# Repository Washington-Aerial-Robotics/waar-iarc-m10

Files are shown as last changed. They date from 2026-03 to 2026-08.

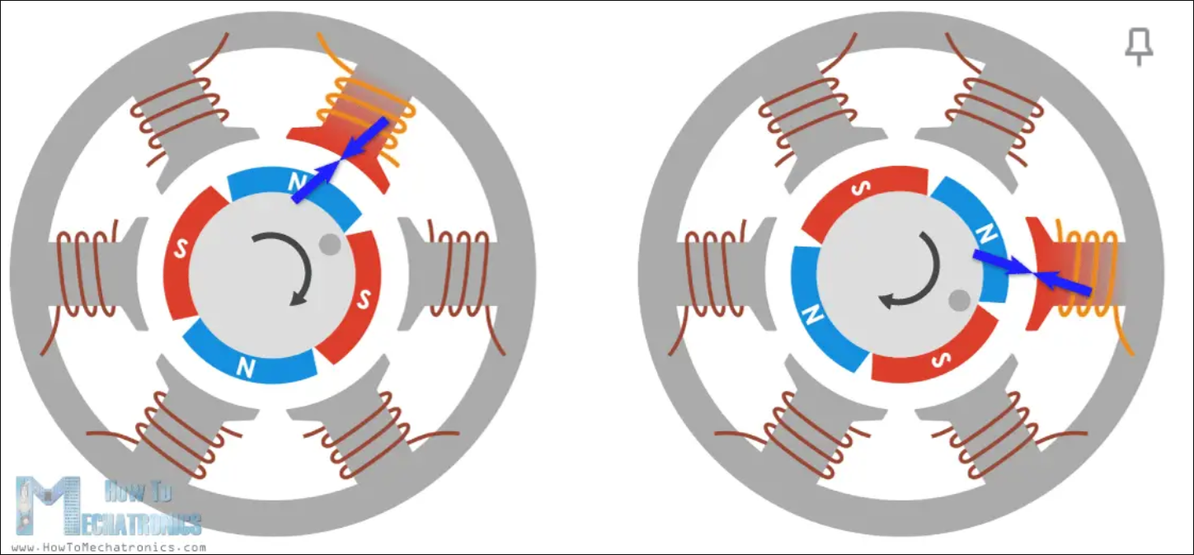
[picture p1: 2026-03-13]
ESP32/docs/images/ESC_MOTOR_BLDC.png

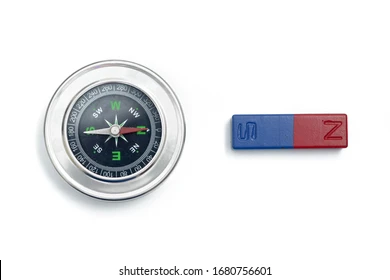
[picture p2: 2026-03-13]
ESP32/docs/images/ESC_MAGNET.png

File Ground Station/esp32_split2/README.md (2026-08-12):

# Flutter Drone Controller GUI

## Overview

This repository implements a **cross-platform Flutter-based drone control interface** for real-time communication with an ESP32 flight controller over TCP/Wi-Fi.

The application provides:

* live TCP console communication (send raw test/debug packets, watch raw firmware output)
* dual joystick flight controls
* ARM / DISARM / KILL safety controls
* voice commands (basic movement, hover, stop)
* responsive portrait + landscape layouts

---

## Getting Started

### Prerequisites

* Flutter SDK, **stable channel** (this project pins `sdk: ^3.9.2` in `pubspec.yaml` — run `flutter --version` and `flutter doctor` to confirm your install satisfies it).
* A phone (Android or iOS) or desktop target to run on. Voice control (`speech_to_text`) is the one feature that's only verified on mobile — don't assume it works on Windows/macOS/Linux builds.
* The drone powered on, with its flight firmware running (`ESP32/KAF_Drone`).

### Install & run

```bash
cd "Ground Station/esp32_split2"
flutter pub get
flutter devices        # confirm your target device/emulator is visible
flutter run            # or pick a device explicitly: flutter run -d <device-id>
```

You can also launch it from VS Code using the configurations in `.vscode/launch.json` (`esp32_split2`, plus profile/release variants).

Platform permissions the app needs are already declared:

* **Android** (`android/app/src/main/AndroidManifest.xml`): `RECORD_AUDIO` (voice control) and `INTERNET` (TCP socket to the drone).
* **iOS** (`ios/Runner/Info.plist`): `NSMicrophoneUsageDescription` and `NSSpeechRecognitionUsageDescription`.

If you add other platforms later, double-check they have equivalent permissions — network/mic access is not implicitly granted everywhere.

---

## Connecting to the drone

The app does **not** join Wi-Fi networks itself — it only opens a TCP socket to an IP/port you give it. You have to join the drone's Wi-Fi network at the OS level (phone Settings → Wi-Fi) *before* connecting from inside the app.

By default, the drone boots as its own open Wi-Fi access point:

* **SSID:** `KAF_Quadcopter_Drone`
* **Password:** none (open network)
* **Drone IP once connected:** `192.168.1.240`
* **TCP port:** `70` (hardcoded in firmware — `WiFiServer server = WiFiServer(70)` in `periph_wifi.cpp`)

> **Heads up:** the Console tab's IP/port fields currently default to `172.20.10.8` / `80` — leftovers from a previous test setup, not the drone's actual defaults. For a stock drone in its default AP mode, clear those fields and enter `192.168.1.240` and `70` instead. If your drone has been reconfigured to join an existing network (STA mode) or a different port, use whatever IP/port it was actually assigned there.

The drone's firmware only accepts **one TCP client at a time** — if another ground station (or a stale connection) is already attached, a new connection attempt will hang or fail until that one disconnects.

### Step by step

1. Power on the drone. It starts broadcasting `KAF_Quadcopter_Drone`.
2. On your phone, join that Wi-Fi network in system settings.
3. Open the app → **Console** tab.
4. Set **Target Drone ID** (single character, default `A` — must match the drone's configured ID).
5. Set **Drone IP** to `192.168.1.240` and **Port** to `70` (see note above).
6. Tap **Connect to drone**. You should see `Connecting…` then `Connected` in the log, and the connection status icon turn green.
7. Use **Send PING** to sanity-check the link — you should see a logged reply.

---

## Using the app

### Console tab

Low-level debug view. Connect/disconnect, change target drone ID, and fire off individual test packets:

* **Send PING** — round-trip check that the link is alive.
* **Get IP** — asks the drone to report its Wi-Fi info.
* **Get Pos** — requests the drone's current position/flight status.
* **Test Control** — sends a single motor-command packet with all four motors at 0.5, independent of the joysticks (useful for a quick bench test with props off).

All traffic is logged as raw hex in **Drone Printout**.

### Remote tab (primary flight interface)

* **Left stick** — throttle (up/down) / yaw (left/right).
* **Right stick** — pitch (forward/back) / roll (left/right).
* **ARM** — starts the app's control loop, which sends motor commands to the drone 4 times per second (every 250ms) based on current stick position.
* **DISARM** — zeroes all stick values and stops the control loop.
* **KILL** — immediately zeroes controls, stops the loop, *and* sends a dedicated kill packet to the drone's firmware (this is the one button that reaches the drone even if the local loop isn't running).
* Live readout of throttle/yaw/pitch/roll is shown in the HUD — note this reflects the app's own stick state, not telemetry reported back by the drone.

**Safety notes:**
* You must be connected *and* armed before sticks or voice commands do anything — the controls are disabled otherwise.
* Once "reconnect after KILL" happens (i.e. you've hit KILL), you must disconnect and reconnect before arming again.

### Voice control

Available on the Remote tab once armed. Tap the mic button and speak one phrase per command (recognized as a single short utterance, not continuous dictation):

| Say | Effect |
|---|---|
| "up" / "go up" / "move up" / "ascend" | increases throttle a step |
| "down" / "go down" / "move down" / "descend" | decreases throttle a step |
| "hover" / "maintain altitude" / "hold altitude" | sets throttle to a fixed hover value, centers pitch/roll/yaw |
| "stop" / "hold" / "stop moving" / "center controls" | centers pitch/roll/yaw, keeps current throttle |
| "forward" / "move forward" / "go forward" | pitches forward briefly, then auto-recenters |
| "backward" / "back" / "move backward" / "go backward" | pitches backward briefly, then auto-recenters |
| "move left" / "slide left" / "strafe left" | rolls left briefly, then auto-recenters |
| "move right" / "slide right" / "strafe right" | rolls right briefly, then auto-recenters |
| "rotate left" / "turn left" / "yaw left" | yaws left briefly, then auto-recenters |
| "rotate right" / "turn right" / "yaw right" | yaws right briefly, then auto-recenters |

Directional commands (forward/back/left/right/rotate) automatically recenter after ~750ms; throttle commands (up/down/hover) persist until changed again.

---

## Architecture

```text
Flutter UI Layer
│
├── Console Screen      — connect/disconnect, raw test packets, log view
├── Remote Control Screen — joysticks, ARM/DISARM/KILL, voice panel
│
▼
Controller Layer
│
├── DroneController        — connection state, stick state, safety commands, 4Hz TX loop
└── VoiceCommandController — wraps speech_to_text, maps phrases to DroneController calls
│
▼
Protocol Layer
│
└── drone_protocol.dart — builds/parses the binary packet format, message-type constants
│
▼
Networking Layer
│
└── TcpClient — raw dart:io Socket, TX/RX byte logging
│
▼
ESP32 firmware (../../ESP32/KAF_Drone)
```

State is shared via `provider`: `main.dart` sets up `TcpClient` → `DroneController` → `VoiceCommandController`, in that dependency order.

---

## Networking protocol

Communication is a **binary packet protocol** over a raw TCP socket (not line-delimited text).

### Packet layout

```text
byte 0: toId        — target device ID (single byte, e.g. 'A' = 0x41)
byte 1: fromId       — sender device ID (app is always 0x47 'G')
byte 2: messageType  — command code (see drone_protocol.dart / ESP32 communication.h)
byte 3: messageId    — rolling sequence number
bytes 4+: payload    — command-specific (e.g. 4 little-endian floats for motor commands)
```

Message-type constants live in `lib/protocol/drone_protocol.dart` and must match `ESP32/KAF_Drone/src/core/communication.h` on the firmware side exactly — they're maintained by hand on both sides, so re-check them against the firmware header if you add or change a command type.

### Motor control packets

Sent by the armed control loop at **4Hz (every 250ms)**: stick values are curve-shaped, mixed into 4 motor values via a standard X-quad mixer, and packed as 4 little-endian 32-bit floats (16-byte payload) behind the standard 4-byte header.

---

## Current file structure

```text
lib/
│
├── main.dart
│
├── controllers/
│   ├── drone_controller.dart
│   └── voice_command_controller.dart
│
├── protocol/
│   └── drone_protocol.dart
│
├── services/
│   └── tcp_client.dart
│
├── screens/
│   ├── drone_tcp_console.dart
│   ├── drone_remote_control.dart
│   └── beta_remote_preview.dart   (UI sandbox — not wired into the app's navigation)
│
└── widgets/
    ├── connect_panel.dart
    ├── log_view.dart
    └── voice_control_panel.dart
```

---

## Known gaps

* No telemetry is actually parsed or displayed from the drone yet — the "live" readout on the Remote tab is the app's own stick state, not anything reported back over the wire.
* ARM/DISARM are local-only; no packet is sent to the drone for either (KILL is the exception — it does send a real packet).
* No automated tests yet.

---

## Tech stack

* Flutter / Dart
* Provider (state management)
* `speech_to_text` (voice recognition)
* Raw TCP sockets (`dart:io`)
* ESP32 firmware backend (`ESP32/KAF_Drone`)

---

## Purpose

This project is being developed as a **real-time drone control GUI prototype** to be used by Washington Aerial Robotics.

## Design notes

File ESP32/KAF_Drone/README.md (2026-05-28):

# KAF Drone Flight Control Software
This is the repositorry for an ESP32 based quadcopter flight controller written in C-like C++ designed for the Washington Aerial Robotics RSO at University of Washington. This flight software is capable of semi-autonomous flight, swarm coordination with other quadcopters, and custom input control. It is able to execute 4-th order polynomial trajectories, position waypoints, direct acceleration control, and manual mode inputs. Some additional features include a web-based ground station and manual controller as well as both indoor and GPS position tracking.

## Setup Instructions

1. Download the contents of the ```waar-iarc-m10/ESP32/KAF_Drone``` directory from the WAAR GitHub [repository](https://github.com/Washington-Aerial-Robotics/waar-iarc-m10/tree/main/ESP32/KAF_Drone), and extract its contents if necessary.
2. From the download, identify the  ```KAF_Drone``` folder, and move this folder to the file location of ```C:\Users\[USERNAME]\Documents\Arduino\libraries\ ``` on your local computer.
3. Check that the ArduinoIDE on your computer has been properly installed and configured. If not, follow the instructions listed in the new member onboarding instructions document provided by Francisco.
4. Open ```C:\Users\[USERNAME]\Documents\Arduino\libraries\KAF_Drone\flashing_examples\firmware_full\firmware_full.ino``` in ArduinoIDE.
5. Connect your flight controller or ESP32 devboard to your computer, then flash the firmware_full Arduino sketch.
6. Verify that the flight controller is operational by checking for the appearance of a WiFi network named "KAF_Quadcopter_Drone" and by a proper serial port print-out at a baudrate of 115200.
7. Connect to the "KAF_Quadcopter_Drone" network, open a web browser, then go to the IP address ```192.168.1.240``` to access the web server ground station.

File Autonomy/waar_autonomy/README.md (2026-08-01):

# WAAR Autonomy — Single-Drone Corridor Explorer

A simulation of a single drone exploring an unknown hazardous environment and certifying a safe passage corridor from start to goal. The codebase follows **Clean Architecture** so every algorithmic layer is independently testable and replaceable.

---

## Setup

```bash
conda env create -f environment.yml
conda activate waar-autonomy
```

---

## Run

```bash
python sim.py                  # animated (default seed 42)
python sim.py --seed 7         # different map
python sim.py --no-anim        # headless, prints progress to console
python sim.py --hazards 40     # denser hazard field
python sim.py --delay 0.02     # slow down animation frame rate
```

---

## What the Simulation Does

The drone starts in the bottom-left corner of an unknown grid and must find and certify a **safe corridor** to the top-right goal.

### Three-Map Architecture

| Map | Grid scale | Contents | Accessible to |
|-----|---|---|---|
| **Map 1** — Ground truth | Fine (`80×60`) | True hazard positions | Infrastructure only — hidden from planner |
| **Map 2** — Visited blocks | Block (`20×15`) | Blocks the drone has entered | Domain `WorldModel` |
| **Map 3** — Detected map | Fine (`80×60`) | `UNKNOWN / FREE / HAZARD / INFLATED` | All use cases |

The fine grid is `K=4` cells per block side, so a `20×15` block grid becomes an `80×60` fine grid.

### Cell States (Map 3)

| State | Colour | Meaning |
|---|---|---|
| `UNKNOWN` | Dark | Not yet visited |
| `FREE` | Light grey | Visited, no hazard |
| `HAZARD` | Red | Confirmed hazard cell |
| `INFLATED` | Orange | Safety buffer around a hazard (radius 3.5 fine cells) |

### Per-Tick Loop

```
UC1  observe_block    → reveal K×K fine cells from Map 1 into Map 3
                        recompute inflation buffer if a hazard was found
UC2  compute_corridor → A* from start to goal on Map 3
                        UNKNOWN cells cost 4× (optimistic planning)
UC3  certify?         → corridor is certified if:
                          clearance ≥ 2.0 fine cells from nearest hazard
                          coverage  = 100% FREE cells (no UNKNOWN on path)
UC4  score_frontiers  → rank unvisited border blocks by:
                          −(travel_cost + goal_cost) + 4.0 × cert_gain
                        cert_gain = UNKNOWN cells on current corridor path
     move drone       → teleport to highest-scoring frontier block
```

---

## Project Structure

```
sim.py                              ← CLI entry point (thin wrapper)

src/
  domain/
    types.py                        ← K, cell states, block↔fine helpers
    world_model.py                  ← WorldModel: map2 (visited) + map3 (detected)
    drone_state.py                  ← DroneState: block + fine-cell position

  ports/
    ground_truth_port.py            ← Protocol: is_hazard(fx, fy)

  adapters/
    sim_ground_truth_adapter.py     ← Wraps GroundTruthMap for the port

  use_cases/
    types.py                        ← CertificationResult DTO
    update_world_model.py           ← UC1: observe block + recompute inflation
    compute_best_corridor.py        ← UC2: A* on fine grid
    evaluate_and_certify_corridor.py← UC3: clearance + coverage check
    score_frontiers_corridor_aware.py← UC4: reverse-Dijkstra + frontier scoring

  application/
    simulator.py                    ← Simulator: wires UC1→UC4 per tick

  infrastructure/
    env/ground_truth_map.py         ← GroundTruthMap (map1, hidden)
    env/map_factory.py              ← Seeded random hazard placement
    visualization/renderer.py       ← build_truth_image / build_detected_image

  experiments/
    config.py                       ← Config dataclass (all tunable parameters)
    run_sim.py                      ← run_headless, run_animated, main()

tests/                              ← Mirrors src/ layout, 43 tests
```

### Layer Import Rules

```
domain/       →  no imports from any other src/ layer
ports/        →  domain/ only
use_cases/    →  domain/, ports/ only
adapters/     →  domain/, ports/, infrastructure/
application/  →  all layers
experiments/  →  all layers (entry points)
```

---

## Configuration

All parameters live in [src/experiments/config.py](src/experiments/config.py):

| Parameter | Default | Effect |
|---|---|---|
| `block_cols` / `block_rows` | 20 / 15 | Grid dimensions in blocks |
| `n_hazards` | 25 | Number of hazard cells placed at random |
| `inflation_radius` | 3.5 | Safety buffer radius (fine cells) |
| `unknown_cost` | 4.0 | A* penalty per UNKNOWN fine cell |
| `min_clearance_cells` | 2.0 | Certification: min distance from any hazard |
| `min_coverage_ratio` | 1.0 | Certification: fraction of path cells that must be FREE |
| `w_cert` | 4.0 | Scoring weight for corridor-overlap uncertainty |
| `max_ticks` | 600 | Simulation budget |

---

## Tests

```bash
pytest              # 43 tests across all layers
pytest tests/domain/
pytest tests/use_cases/
pytest tests/application/   # includes full integration test (seed 42, tick 263)
```

---

## Example Output (headless)

```
Seed=42  blocks=20x15  fine=80x60  K=4  hazards=25
  tick=  50  corridor=yes  clearance=3.61  coverage=94%
  tick= 100  corridor=yes  clearance=3.61  coverage=94%
  tick= 150  corridor=yes  clearance=3.61  coverage=94%
  tick= 200  corridor=yes  clearance=3.61  coverage=95%
  tick= 250  corridor=yes  clearance=3.61  coverage=90%
  tick= 263  corridor=yes  clearance=3.61  coverage=100%
elapsed=4.64s

✅  CERTIFIED at tick 263  clearance=3.61 fine-cells  path_len=93 fine-cells
```

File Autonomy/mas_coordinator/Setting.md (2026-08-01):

# A) For Each drone (×4) 

### 1. `explorer_node` (Kevin - Skipp what he did here)
---

### 2. `p2p_sync_node` 

* Implements **Scheme B sync window**: neighbor graph + hello/ack + missing delta exchange

* Performs **belief fusion**:

  * mine belief clustering / confidence update
  * (optional) tile uncertainty fusion

* **Subscribes/Publishes:**

```
/team/pose_beacon
/team/sync_hello
/team/sync_ack
/team/mine_delta
(optional) /team/tile_delta
```

* (optional) publishes locally:

```
/drone_i/local_belief
```

---

### 3. `p2p_task_node` 

* Fully **P2P task auction system**

Components:

* announce
* claim
* result
* claim window

The **winner sends `task_cmd` to the local explorer** (interrupting exploration).

* **Subscribes/Publishes:**

```
/team/task_announce
/team/task_claim
/team/task_result
```

* **Local subscriptions**

```
/drone_i/mine_candidates
/drone_i/status
```

---

### 4. `mission_logic_node`

(merge it into `p2p_task_node` or independent)

Responsibilities:

* Runs the **State Machine + Behavior Tree runner**
  (each drone runs its own copy)
* Manages:

  * timers
  * geofence
  * time thresholds
  * state transitions
* Sends `task_cmd` to the local explorer
* (optional) broadcasts `mode_beacon` for team observation/consistency

---

# B) State Machine Definition

```
BOOT → SURVEY → VERIFY_TAG → PATH_VERIFY → CONVERGE → FINISH
```

For each state we define:

* **Entry condition**
* **Exit condition / transition**
* **Primary objective**
* **Possible P2P task types**

---

# 1) BOOT

### Objective

System initialization: network ready, localization ready.

### Entry

* System startup automatically enters **BOOT**

### Actions

(Not part of the main BT — usually an initialization sequence)

* Initialize ROS2 publishers/subscribers
* Initialize FastDDS domain
* Start publishing `pose_beacon`
  (even if still at origin)
* Create neighbor table (can start empty)
* Start sync node (able to receive hello/ack)

### Exit → SURVEY

Conditions:

```
pose_valid == true
explorer_node_ready == true
time_since_start < timeout_boot
```

Optional:

```
at least N_min_neighbors pose_beacon detected
```

(In simulation this requirement can be skipped)

---

# 2) SURVEY

### Objective

Maximize **coverage**, accumulate **mine beliefs**, maintain **team safety**, and keep **P2P synchronization active**.

### Entry

* From **BOOT**
* Or return from **VERIFY_TAG**

### Exit

```
→ VERIFY_TAG
    if local drone wins a verify task auction

→ PATH_VERIFY
    if remaining_time < T_path_verify_start (recommended: 120 s)

→ CONVERGE
    if remaining_time < T_converge_start (recommended: 90 s)

→ FINISH
    if remaining_time < T_finish (e.g., 5–10 s)

→ FAILSAFE (optional)
    severe risk (unsolvable collision / control failure)
```

### Possible P2P Tasks During SURVEY

* `VERIFY_TAG` (mine candidate verification)

Optional:

* `YIELD` (collision avoidance)
  but usually handled locally by the safety layer.

---

# 3) VERIFY_TAG

### Objective

Perform **close-range verification of a mine candidate**
(e.g., AprilTag / close inspection).

### Entry

* Drone wins `VERIFY_TAG(task_id)` during claim window

OR

* Local detection with deterministic self-assignment
  (not recommended — causes duplicate verification)

### Exit

```
→ SURVEY
    task completed (confirmed / rejected / uncertain)

→ CONVERGE / PATH_VERIFY
    if time thresholds are reached

→ FAILSAFE
    geofence violation or unresolved collision
```

### Task Completion Conditions

* Reach target radius `r_verify` (e.g., 1–2 m)
* Stay for `t_dwell` (e.g., 2–5 s)
* Acquire tag evidence or fail
* Publish `/team/task_result`

---

# 4) PATH_VERIFY

### Objective

Before entering **CONVERGE**, reduce uncertainty along the **safe path corridor**:

* narrow segments
* low-confidence mines
* path buffer regions

### Entry

```
remaining_time < T_path_verify_start (recommended: 120 s)
```

or (advanced trigger)

```
W_min < threshold
uncertainty_along_path high
```

### Exit

```
→ CONVERGE
    remaining_time < T_converge_start (recommended: 90 s)

→ VERIFY_TAG
    high-priority mine appears

→ FINISH
    time limit reached
```

### P2P Tasks in PATH_VERIFY

* `BECOME_PATH_VERIFIER`
* `VERIFY_PATH_SEGMENT`
* `RESCAN_PATH_BUFFER`

**MVP**

Select **1 drone as Path Verifier**,
while the other **3 continue exploration / gap filling**.

---

# 5) CONVERGE

### Objective

Final convergence phase:

* align **team beliefs**
* rescan **critical areas**
* final verification before output

### Entry

```
remaining_time < T_converge_start (recommended: 90 s)
```

### Exit → FINISH

```
remaining_time < T_finish
```

### Possible P2P Tasks

* `BECOME_VERIFIER`
* `VERIFY_TAG` (only for mines affecting path)
* `RESCAN` (critical path segments / buffers)

---

# 6) FINISH

### Objective

Stop new tasks and **freeze final outputs**.

### Entry

```
remaining_time < T_finish
```

### Actions

* Stop new `task_announce`
* Explorer enters **hold/hover**
* Publish final summaries:

  * mine beliefs
  * safe path (if available)

### Exit

Competition ends → node shutdown.

---

# C) Behavior Tree (BT) Structure Per State

**Key principle**

The **BT skeleton remains the same**, but different states modify:

* **Task Executor goals**
* **Exploration policy weight**

---

# Shared BT Skeleton (All States)

Priority Selector (top = highest priority)

1. **Safety / Collision Guard**
   local collision avoidance and speed limits

2. **Geofence + Time Guard**
   pull back from boundary, trigger state transitions

3. **Failure Monitor**
   detect perception/control anomalies

4. **Task Executor**
   execute assigned / won tasks

5. **Exploration Policy**
   frontier-based exploration

6. **P2P Sync Manager**
   neighbor sessions + delta exchange

7. **P2P Task Listener**
   receive announce / claim / result
   update state / task queue

8. Logging / metrics

⚠ Important:
**Task Listener must always run** —
it is the **event source that triggers state transitions**.

---

# BOOT Behavior Tree

* Safety / Geofence / Fault: mostly idle (hover)
* Sync: hello/ack allowed
* Task: ignore incoming tasks

---

# SURVEY Behavior Tree (Primary Operation Mode)

* Task Executor: only execute **VERIFY_TAG tasks already won**
* Exploration Policy: **main active component**
* Sync Manager: normal frequency
* Task Listener: allow verify auctions

---

# VERIFY_TAG Behavior Tree (Task Preemption)

* Task Executor executes full verification sequence:

```
go_to_target
→ descend / approach
→ dwell / scan
→ report result
```

* Exploration: disabled or very low priority
* Sync Manager: still running
* Task Listener: receives tasks but usually does not claim new ones

---

# PATH_VERIFY Behavior Tree

Two possible roles:

---

### A) Path Verifier (won `BECOME_PATH_VERIFIER`)

* Task Executor prioritizes:

```
VERIFY_PATH_SEGMENT
RESCAN_PATH_BUFFER
```

* Exploration disabled or very low
* Sync more aggressive

---

### B) Non-Verifier Drone

* Continue exploration but **less aggressive**
* May still participate in high-priority `VERIFY_TAG` auctions

---

# CONVERGE Behavior Tree

* Task Executor only performs **final critical tasks**:

  * low-confidence mines near path
  * critical segment rescans

* Exploration mostly disabled

* Sync frequency increased

* Task Listener may restrict tasks to high priority

---

# FINISH Behavior Tree

* Stop announcing / claiming tasks
* Explorer enters **hold / hover**
* Sync reduced or stopped
* Publish final logs / summaries

---

# D) Suggested Time Thresholds

Example parameters:

```
T_total = 7:00

T_path_verify_start = 120 s
T_converge_start = 90 s
T_finish = 10 s
```

Meaning:

* Enter **PATH_VERIFY** when **2 minutes remain**
* Enter **CONVERGE** when **90 seconds remain**
* Freeze system **10 seconds before the end**

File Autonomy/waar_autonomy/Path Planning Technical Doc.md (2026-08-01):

# WAAR Autonomy — Technical Handover Document

**Author:** *Kevin*  
**Scope:** Single-drone corridor exploration simulation (`sim.py`) and supporting architecture  

---

## 0. Purpose

This document records the design decisions, implementation details, and open work items for the single-drone autonomy module. It is intended to provide sufficient context for an incoming engineer to maintain and extend the codebase without loss of intent.

Multi-agent coordination (UC5, UC6) and mission-level planning are out of scope for this document and are covered separately by other team members.

---

## 1. Problem Statement

The drone operates in an unknown environment containing landmine-like hazards. The objective is to find and certify a safe traversal corridor from a start region to a goal region as quickly as possible, subject to the following constraints:

- The corridor must maintain a minimum clearance from all detected hazards.
- Every cell on the certified path must be confirmed free (no remaining uncertainty).
- The total mission budget is 600 ticks in simulation.

The fundamental planning tension is between **broad exploration** (reducing global uncertainty) and **focused certification** (resolving uncertainty specifically along the most promising corridor candidate). The scoring strategy described in §3.4 is the core contribution addressing this tension.

---

## 2. Implementation Scope

This work covers the single-drone planning loop only.

| Responsibility | Status |
|---|---|
| World model maintenance (two-scale maps) | Implemented |
| Corridor search via A\* on fine cell grid | Implemented |
| Corridor certification (clearance + coverage) | Implemented |
| Corridor-aware frontier scoring (Reverse Dijkstra + `cert_gain`) | Implemented |
| Hazard inflation on fine cell grid | Implemented |
| Multi-agent assignment (UC5, UC6) | Out of scope — other team member |
| SLAM / pose estimation | Out of scope — external system |
| Hazard detection model | Out of scope — external system |
| Flight controller | Out of scope — external system |

---

## 3. Design Decisions

### 3.1 Two-Scale World Representation

The world model maintains two map resolutions concurrently.

| Map | Scale | Grid | Purpose | Accessible to |
|-----|---|---|---|---|
| Map 1 — Ground truth | Fine | 80 × 60 | True hazard positions | `infrastructure/` only — hidden from planner |
| Map 2 — Visited blocks | Coarse | 20 × 15 blocks | Frontier detection, visited tracking | Domain `WorldModel` |
| Map 3 — Detected map | Fine | 80 × 60 (K = 4 cells/block side) | Hazard state, inflation zones, A\*, clearance metrics | All use cases |

**Rationale.** Running A\* at block resolution produces clearance measurements too coarse for safety guarantees — a hazard can fall between block centres and go undetected by the path planner. Running frontier scoring at fine-cell resolution is computationally wasteful for assignment decisions. The two-scale design confines precise safety reasoning to the fine grid while keeping assignment decisions at block scale (O(1) lookup per frontier).

The bridge between scales is a single Reverse Dijkstra pass from the goal over Map 3, executed once per tick. Every frontier block's `goal_cost` is retrieved by looking up the cost at its block-centre fine cell — no per-block A\* is required.

### 3.2 A\* Cost Model with Optimistic UNKNOWN Penalty

A\* operates on Map 3 with the following cell costs:

| Cell State | Cost |
|---|---|
| `FREE` | 1.0 |
| `UNKNOWN` | 4.0 |
| `HAZARD` | ∞ |
| `INFLATED` | ∞ |

**Rationale.** Assigning `UNKNOWN` a cost of ∞ prohibits path planning through unexplored space, forcing the drone to achieve full coverage before committing to any corridor — an overly conservative strategy incompatible with the time budget. Assigning `UNKNOWN` a cost equal to `FREE` (1.0) produces corridor candidates that route indiscriminately through unmapped regions. The value 4.0 implements optimistic planning: the planner commits to a corridor hypothesis through unknown space while maintaining a preference for confirmed-free paths. This parameter (`unknown_cost` in `Config`) is a primary tuning target.

### 3.3 Hazard Inflation into UNKNOWN Cells

On hazard detection, a circular inflation zone of radius 3.5 fine cells is immediately written as `INFLATED` (cost ∞) on Map 3. Inflation propagates into `UNKNOWN` neighbours, not only confirmed cells.

**Rationale.** Restricting inflation to confirmed cells would allow A\* to route through a buffer zone that may contain additional hazard extent due to positional uncertainty in the detection. Propagating into `UNKNOWN` neighbours ensures the path planner reroutes conservatively before those cells have been physically visited, preventing the drone from committing to a corridor that a subsequent observation would invalidate.

### 3.4 Corridor-Aware Frontier Scoring

Frontier blocks are scored by:

```
score(block) = −(travel_cost + goal_cost) + w_cert × cert_gain
```

| Term | Definition |
|---|---|
| `travel_cost` | Euclidean distance from the drone's current fine-cell position to the block centre. |
| `goal_cost` | Reverse Dijkstra cost from the block centre to the goal, precomputed on Map 3. |
| `cert_gain` | Count of `UNKNOWN` fine cells within this block that lie on the current A\* corridor path. |

**Rationale.** Pure goal-biased exploration moves the drone efficiently toward the goal but provides no incentive to resolve uncertainty along the current corridor candidate. A strategy that maximises `cert_gain` exclusively converges on the present corridor at the expense of discovering better alternatives. The combined formula is self-regulating: when `cert_gain` along the current corridor approaches zero (coverage near 100%), `travel_cost + goal_cost` dominates and the drone advances toward new frontiers. When A\* identifies a new corridor candidate with unresolved cells, `cert_gain` increases and the drone pivots to resolve it. The weight `w_cert = 4.0` was selected empirically and is exposed as a tunable parameter.

### 3.5 Certification Criteria

A corridor is certified when both conditions are satisfied simultaneously:

- `clearance ≥ 2.0 fine cells` — minimum distance from any hazard or inflated cell to any cell on the path.
- `coverage = 100%` — no `UNKNOWN` cells remain on the A\* path; all cells are confirmed `FREE`.

**Rationale.** Certifying a corridor with any remaining `UNKNOWN` cells is equivalent to certifying a path that may contain undetected hazards. The 100% coverage requirement ensures the drone has physically observed every cell on the output path prior to certification. The threshold is configurable (`min_coverage_ratio`) to allow relaxation where time constraints take precedence.

---

## 4. Implementation

The simulation is structured with Clean Architecture. `sim.py` is a thin CLI entry point; all logic resides under `src/`.

### Layer Structure and Import Rules

```
sim.py                               ← CLI entry point (no logic)
src/
  domain/                            ← Pure data types and invariants
  ports/                             ← Protocol definitions (interfaces)
  adapters/                          ← Port implementations
  use_cases/                         ← Business logic, no framework dependencies
  application/                       ← Tick loop orchestration
  infrastructure/                    ← Ground truth map, renderer
  experiments/                       ← Config and entry points
tests/                               ← Mirrors src/ layout
```

| Layer | May import from |
|---|---|
| `domain/` | Nothing within `src/` |
| `ports/` | `domain/` only |
| `use_cases/` | `domain/`, `ports/` |
| `adapters/` | `domain/`, `ports/`, `infrastructure/` |
| `application/` | All layers |
| `experiments/` | All layers |

Map 1 (ground truth) is accessible to `infrastructure/` only. No use case reads it directly.

### Use Cases

| ID | Function | Module | Status |
|----|---|---|---|
| UC1 | Observe block; update Map 3; recompute inflation | `use_cases/update_world_model.py` | Implemented |
| UC2 | A\* on Map 3; compute corridor candidate | `use_cases/compute_best_corridor.py` | Implemented |
| UC3 | Evaluate clearance and coverage; certify | `use_cases/evaluate_and_certify_corridor.py` | Implemented |
| UC4 | Reverse Dijkstra; score and rank frontiers | `use_cases/score_frontiers_corridor_aware.py` | Implemented |

### Per-Tick Loop

```
UC1  observe_block     → reveal K×K fine cells from Map 1 into Map 3
                         recompute inflation if a hazard was found
UC2  compute_corridor  → A* from start to goal on Map 3
UC3  certify           → clearance ≥ 2.0 AND coverage = 100%
                         if CERTIFIED: emit CorridorReport, halt
UC4  score_frontiers   → Reverse Dijkstra (1× per tick) over Map 3
                         score(b) = −(travel_cost + goal_cost) + w_cert × cert_gain
     move              → advance drone to highest-scoring frontier block
```

UC2 executes before UC4 so that `cert_gain` is evaluated against the latest corridor candidate within the same tick.

### Integration Benchmark

Seed 42, default configuration:

```
✅  CERTIFIED at tick 263  clearance=3.61 fine-cells  path_len=93 fine-cells
elapsed=4.64s
```

Certification at tick 263 of 600. This result is locked as the integration test in `tests/application/` and must remain stable across refactors.

---

## 5. File Index

| Path | Description |
|---|---|
| `sim.py` | CLI entry point — no logic |
| `src/domain/types.py` | Cell state enum, K constant, block↔fine coordinate helpers |
| `src/domain/world_model.py` | `WorldModel`: Map 2 (visited blocks) + Map 3 (detected fine cells) |
| `src/domain/drone_state.py` | `DroneState`: block and fine-cell position |
| `src/ports/ground_truth_port.py` | `GroundTruthPort` protocol: `is_hazard(fx, fy)` |
| `src/adapters/sim_ground_truth_adapter.py` | Wraps `GroundTruthMap` behind `GroundTruthPort` |
| `src/use_cases/types.py` | `CertificationResult` DTO |
| `src/use_cases/update_world_model.py` | UC1 |
| `src/use_cases/compute_best_corridor.py` | UC2 |
| `src/use_cases/evaluate_and_certify_corridor.py` | UC3 |
| `src/use_cases/score_frontiers_corridor_aware.py` | UC4 |
| `src/application/simulator.py` | Wires UC1–UC4 per tick |
| `src/infrastructure/env/ground_truth_map.py` | `GroundTruthMap` (Map 1, hidden from planner) |
| `src/infrastructure/env/map_factory.py` | Seeded random hazard placement |
| `src/infrastructure/visualization/renderer.py` | `build_truth_image` / `build_detected_image` |
| `src/experiments/config.py` | `Config` dataclass — all tunable parameters |
| `src/experiments/run_sim.py` | `run_headless`, `run_animated`, `main()` |
| `tests/` | 43 tests mirroring `src/` layout |

---

## 6. Open Items

### Immediate Next Steps

**1. Raspberry Pi Deployment and Compute Profiling**

The immediate priority is to deploy `sim.py` on the target onboard hardware (Raspberry Pi) and profile per-tick compute cost. The purpose is twofold: validate that the planning loop is feasible within the onboard resource budget, and produce concrete timing data to inform how the tick budget should be allocated across the full multi-drone system.

Metrics to collect per tick:

| Metric | Relevance |
|---|---|
| A\* wall time (UC2) | Dominant cost; scales with fine grid size and UNKNOWN cell density |
| Reverse Dijkstra wall time (UC4) | Fixed O(N) per tick over the fine grid |
| Total tick wall time | Must fit within the real-time control loop period |
| Peak memory usage | Two fine grids (80×60 float32) plus A\* open set |

Profiling should cover multiple seeds and hazard densities (`n_hazards` 10–50) to capture best- and worst-case costs. If A\* wall time is the bottleneck, the primary mitigation is reducing `K` (fine cells per block side) from 4 to 2 or 3, reducing the fine grid from 4,800 to 900–2,025 cells at the cost of clearance measurement precision.

**2. Parameter Sweep**

Following the RPi profiling, run a systematic sweep to identify the configuration that minimises `time_to_certified` within the confirmed compute budget. Key parameters: `unknown_cost` (2–8), `w_cert` (1–8), `inflation_radius` (2–5), `min_coverage_ratio` (0.8–1.0). Sweep across multiple seeds and hazard densities; report `time_to_certified`, `corridor_width`, `corridor_length`.

### Deferred Work

| Item | Notes |
|---|---|
| Probabilistic hazard fusion | `p_detect` is stored but not applied in map updates. A Bayesian update rule would replace the current binary write. |
| Localization uncertainty propagation | Inflation radius is currently fixed. It should scale with pose covariance when that data becomes available from the SLAM module. |
| Verification scheduling | A targeted re-observation pass for corridors that are near the coverage threshold but not yet certifiable. |
| Corridor-as-region width optimisation | The certified corridor is a centerline path. Explicit width optimisation would treat it as a band and maximise minimum clearance across its full extent. |

### Architectural Invariants

| Rule | Rationale |
|---|---|
| A\* and Dijkstra reside in `use_cases/`, not `domain/` | Domain entities are pure data structures. Algorithms in the domain layer cannot be independently tested or swapped without modifying the entities themselves. |
| Grid parameters (`block_cols`, `block_rows`, `inflation_radius`) are always read from `Config` | Hardcoded grid parameters break the parameter sweep and require source edits for map-scale changes. |
| `adapters/` contains no domain logic | Adapter code translates data formats only. Business rules in adapters become coupled to the simulation backend and cannot be unit-tested in isolation. |

---

## 7. Suggested Reading Order

1. This document
2. `README.md` — setup, run commands, configuration reference
3. `src/experiments/config.py` — all tunable parameters; review before modifying behaviour
4. `src/application/simulator.py` — tick loop; shows how UC1–UC4 are composed
5. `src/use_cases/score_frontiers_corridor_aware.py` — primary algorithmic contribution; `cert_gain` logic is here
6. `system_design.md` — full entity and use-case specification; reference when extending the module

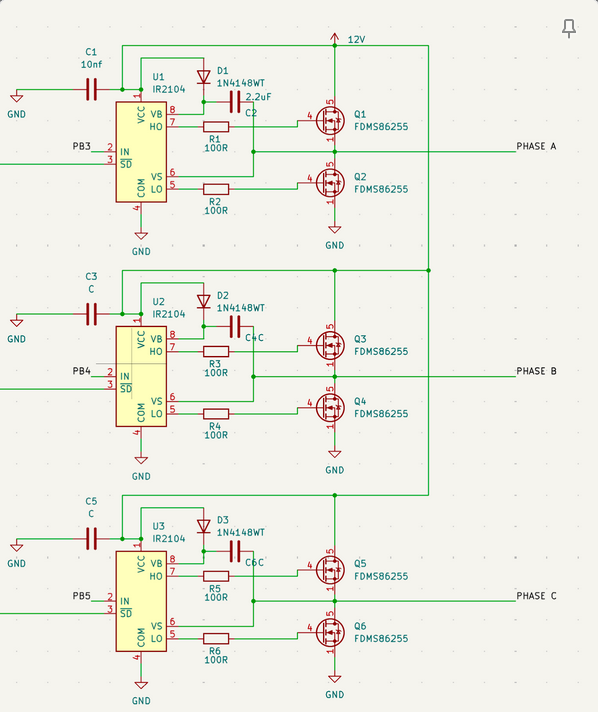
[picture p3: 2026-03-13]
ESP32/docs/images/ESC_SCHEMATIC.png

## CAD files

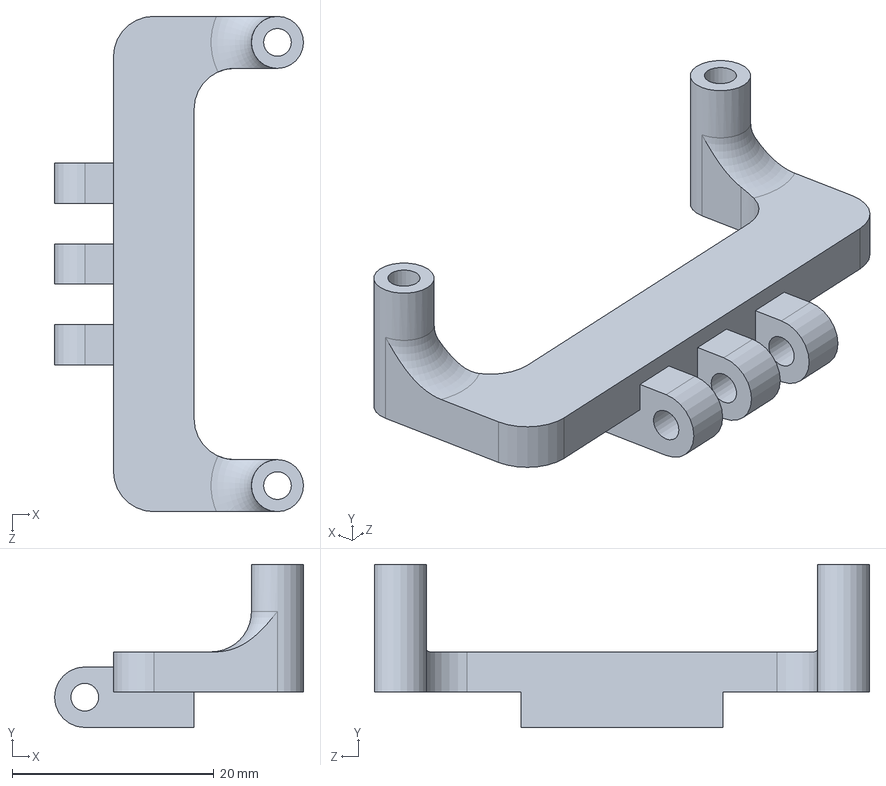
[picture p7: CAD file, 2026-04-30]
Hardware/CAD/FRAME/FRONT_CAMERA_BASE_WAAR_VER_3.SLDPRT
24.7 x 16.1 x 49.1 mm

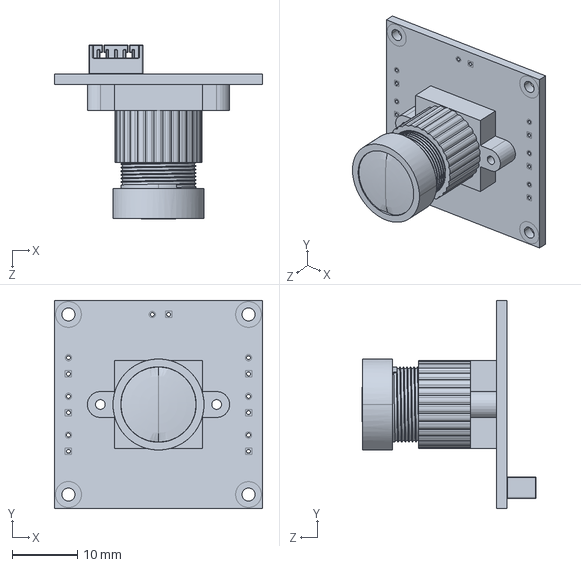
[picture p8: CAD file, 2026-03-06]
Hardware/CAD/Models/MONO_CAMERA_VER_1.SLDPRT
32.0 x 32.0 x 26.8 mm

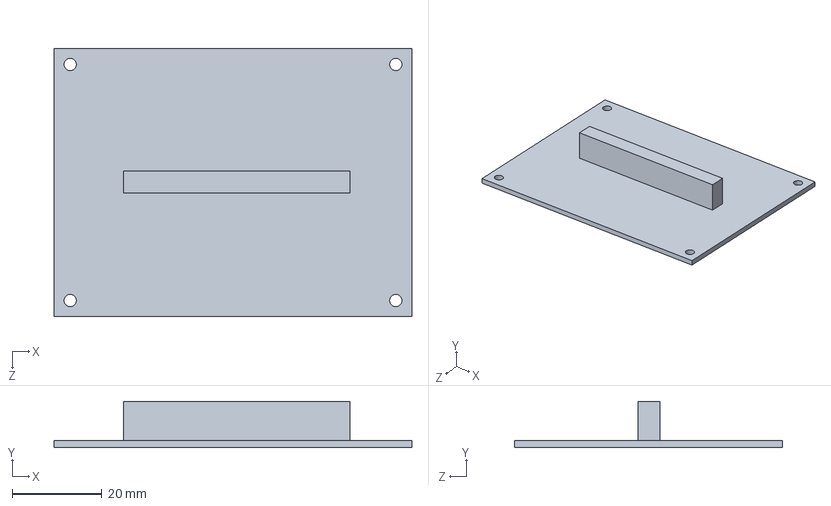
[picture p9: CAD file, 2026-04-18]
Hardware/CAD/PERIPHERALS/PCB_MODEL_WAAR_VER_1.SLDPRT
80.0 x 10.4 x 60.0 mm

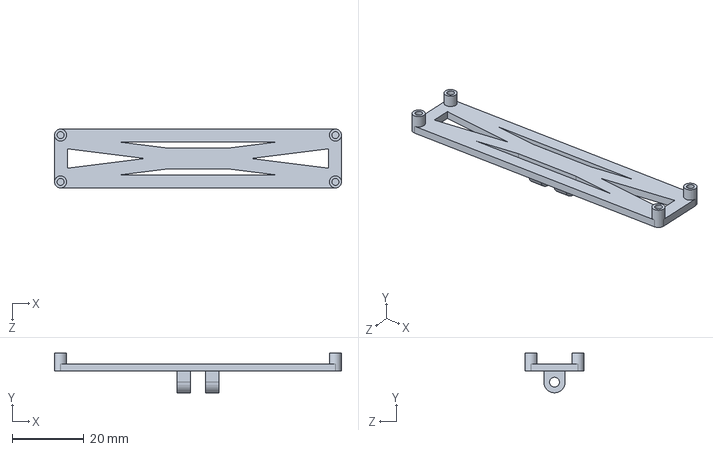
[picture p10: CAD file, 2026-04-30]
Hardware/CAD/FRAME/FRONT_CAMERA_HOLDER_WAAR_VER_3.SLDPRT
80.1 x 11.1 x 16.5 mm

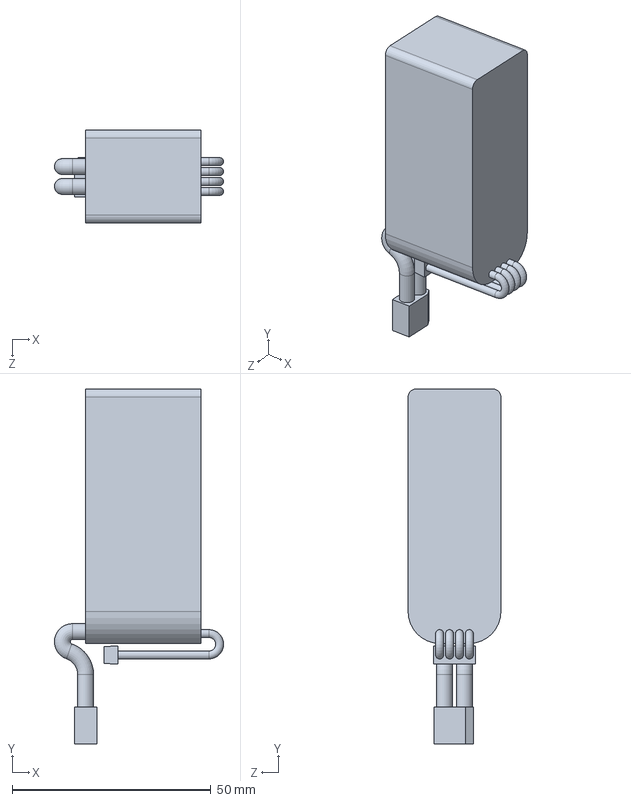
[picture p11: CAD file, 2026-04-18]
Hardware/CAD/PERIPHERALS/BATTERY_MODEL_WAAR_VER_1.SLDPRT
42.6 x 89.3 x 23.4 mm

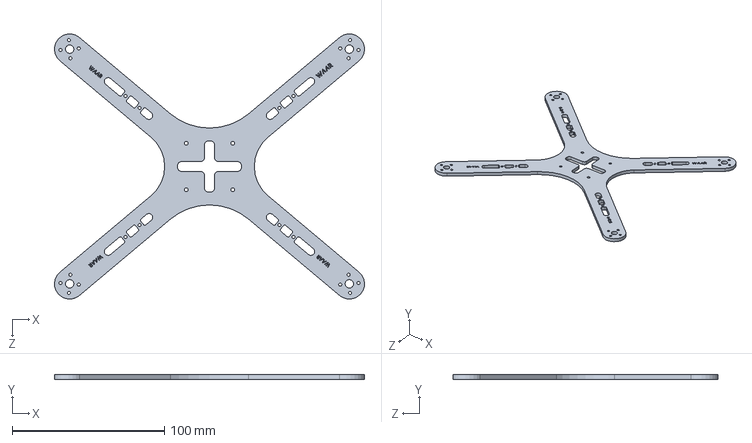
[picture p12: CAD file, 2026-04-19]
Hardware/CAD/FRAME/DRONE_FRAME_WAAR_WIN_VER_6.SLDPRT
203.8 x 3.00 x 174.2 mm

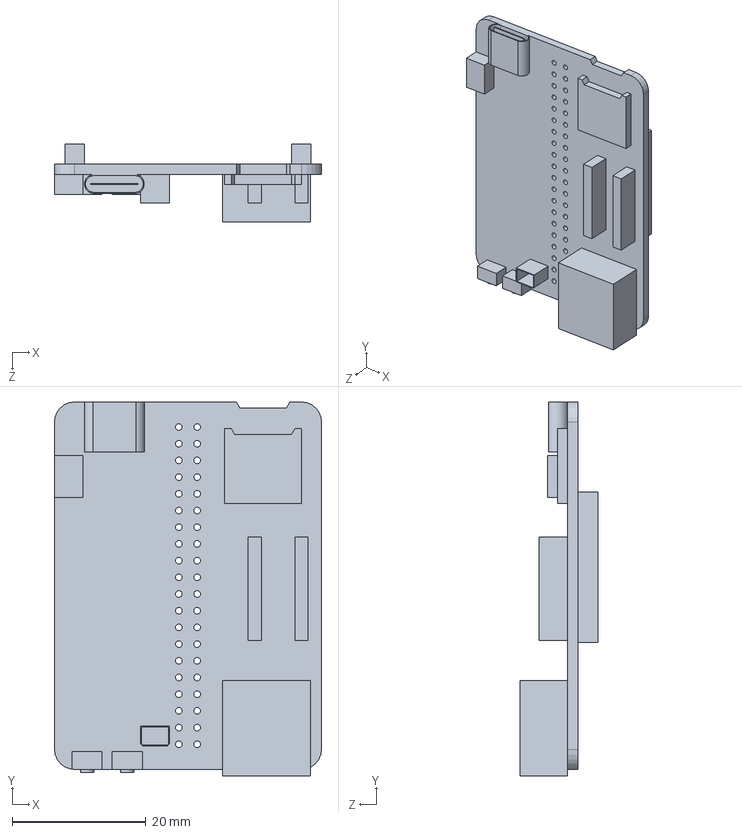
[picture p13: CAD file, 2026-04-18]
Hardware/CAD/PERIPHERALS/CARRIERBOARD_WAAR_VER_2.SLDPRT
40.0 x 56.0 x 11.7 mm

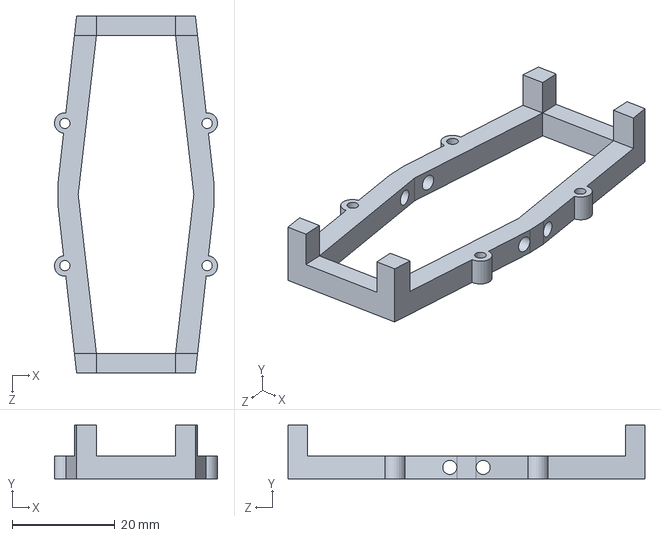
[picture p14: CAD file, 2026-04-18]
Hardware/CAD/FRAME/BATTERY_HOLDER_WAAR_VER_3.SLDPRT
31.7 x 10.5 x 69.5 mm

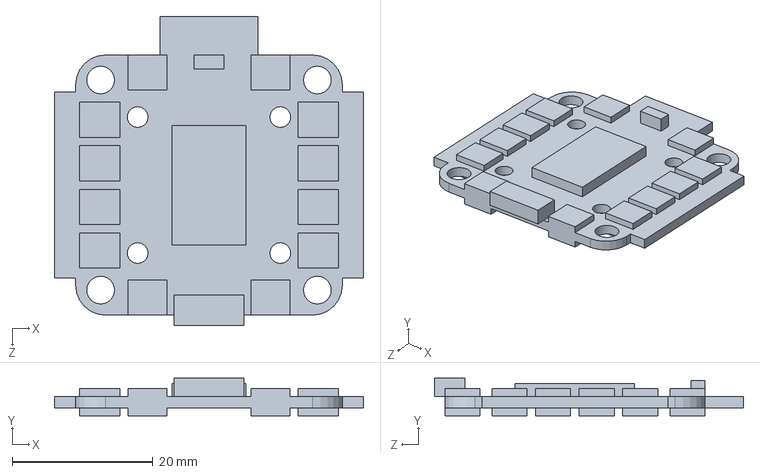
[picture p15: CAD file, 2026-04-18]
Hardware/CAD/PERIPHERALS/ESC_WAAR_VER_1.0.SLDPRT
44.0 x 5.36 x 44.0 mm

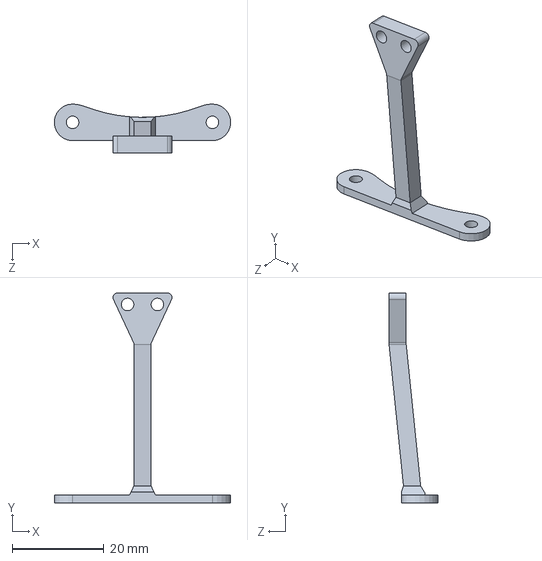
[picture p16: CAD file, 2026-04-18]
Hardware/CAD/FRAME/BATTERY_ARM_WAAR_VER_4.SLDPRT
38.5 x 45.8 x 10.7 mm

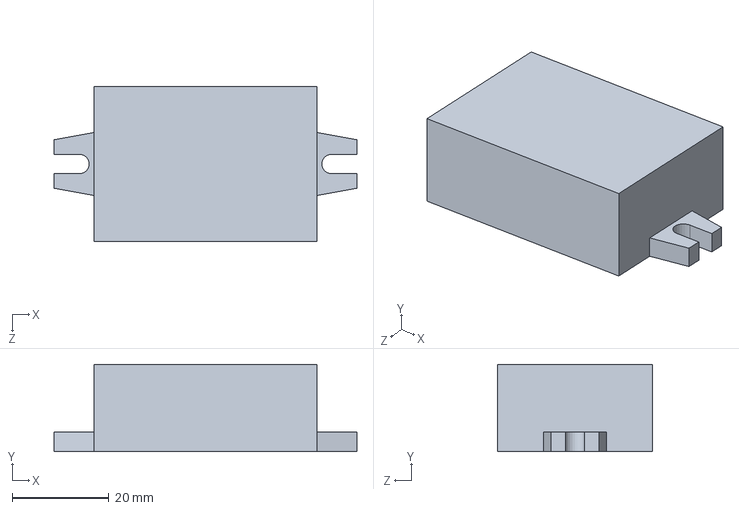
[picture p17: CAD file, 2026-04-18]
Hardware/CAD/PERIPHERALS/DC_DC_CONV_MODEL_WAAR_VER_1.SLDPRT
62.5 x 18.0 x 32.0 mm

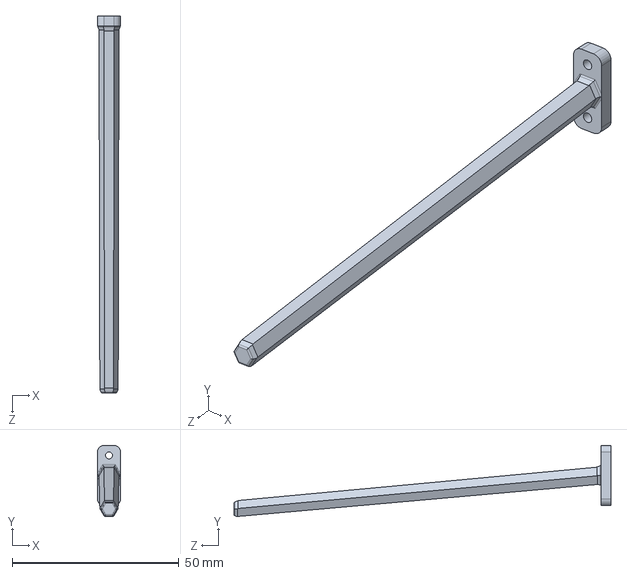
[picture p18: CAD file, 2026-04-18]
Hardware/CAD/FRAME/LEG_WAAR_VER_4.SLDPRT
7.00 x 21.3 x 113.0 mm

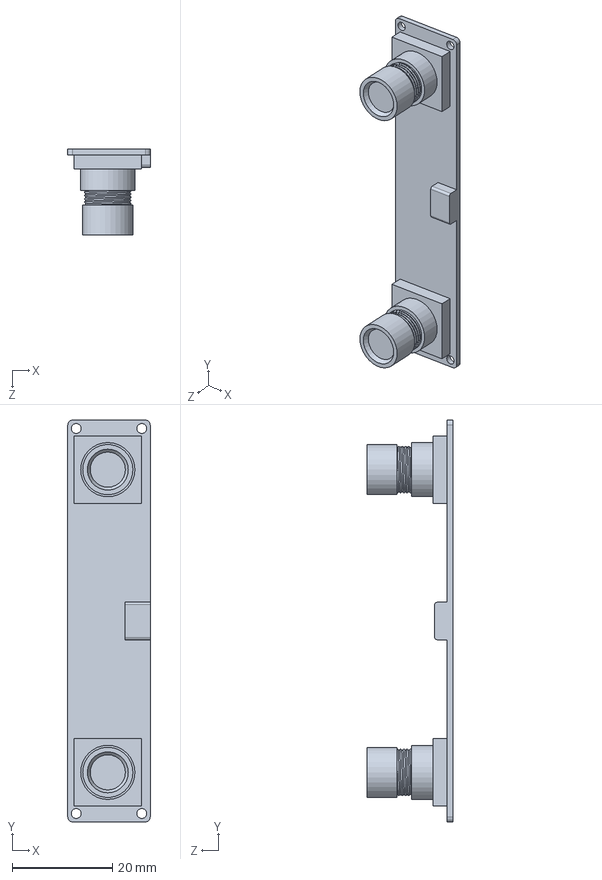
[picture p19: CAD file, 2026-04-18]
Hardware/CAD/PERIPHERALS/FRONT_CAMERA_VER_1.SLDPRT
16.5 x 80.1 x 17.2 mm

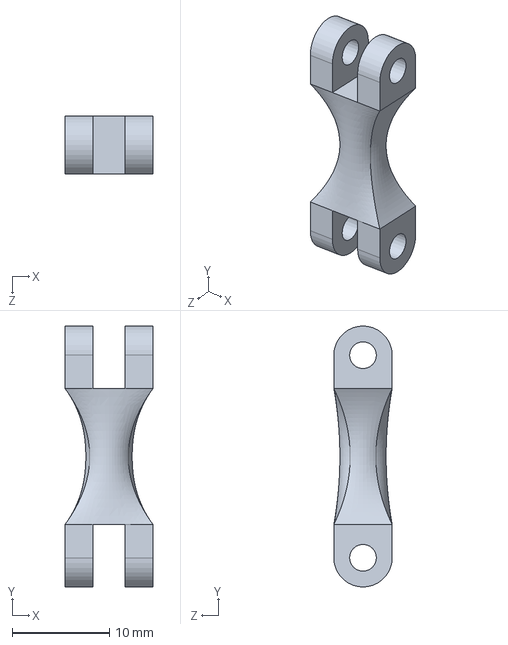
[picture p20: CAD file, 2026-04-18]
Hardware/CAD/FRAME/FRONT_CAMERA_EXTENDER_WAAR_VER_2.SLDPRT
9.06 x 26.8 x 6.00 mm

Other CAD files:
Hardware/CAD/ASSEMBLY.SLDASM
Hardware/CAD/PERIPHERALS/PROPELLER_BLADE_WAAR_VER_1.SLDPRT
Hardware/CAD/FRAME/DC_DC_HOLDER_WAAR_VER_3.SLDPRT
Hardware/CAD/PERIPHERALS/RASPBERRY_PI_CM5_WAAR_VER_1.SLDPRT
Hardware/CAD/FRAME/BOTTOM_CAMERA_BRACKET_WAAR_VER_1.SLDPRT
Hardware/CAD/FRAME/MOTOR_VIBRATION_DAMPENER_WAAR_VER_2.SLDPRT
Hardware/CAD/FRAME/PCB_HOLDER_WAAR_VER_2.SLDPRT
Hardware/CAD/FRAME/TEMPORARY_PCB_HOLDER_WAAR_VER_1.SLDPRT
Hardware/CAD/Frame_Parts/PCB_HOLDER_WAAR_VER_2.SLDPRT
Hardware/CAD/PERIPHERALS/PROPELLER_MOTOR_WAAR_VER_1.SLDPRT
Hardware/CAD/PERIPHERALS/SCREWS/92000A004_Passivated 18-8 Stainless Steel Pan Head Phillips Screws.SLDPRT
Hardware/CAD/PERIPHERALS/SCREWS/M2.5.SLDPRT
Hardware/CAD/PERIPHERALS/TEMPORARY_PCB_MODEL_ADAPTER_WAAR_VER_1.SLDPRT

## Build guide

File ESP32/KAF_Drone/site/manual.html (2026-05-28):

Master Panel

# KAF Drone Ground Station Terminal

Source Code (https://github.com/Washington-Aerial-Robotics/waar-iarc-m10/tree/Firmware-Kent/ESP32/KAF_Drone)

Disarm Drone Kill Manual Hover Enable Safety

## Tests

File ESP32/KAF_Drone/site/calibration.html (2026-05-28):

Master Panel

# KAF Drone Ground Control Calibration

Source Code (https://github.com/Washington-Aerial-Robotics/waar-iarc-m10/tree/Firmware-Kent/ESP32/KAF_Drone)

Data Management

Download Full Info Upload Full Info Reset Full Info Save Full Info Download Calibration Upload Calibration

Position

Pos X m Pos Y m Pos Z m

Sensor Filter Values

Sensor Gain Offset Stdev GYRO X GYRO Y GYRO Z ACCEL X ACCEL Y ACCEL Z MAG X MAG Y MAG Z BARO TEMP GPS LAT GPS LNG GPS ALT DW X DW Y DW Z

Calibration & Tuning

Sensor Calibration Magnetometer Calibration Simulation PID Tuning Physical PID Tuning Set Drone System ID Set PID Response Data

Velocity

Veloc X m/s Veloc Y m/s Veloc Z m/s

Control Constants

Angle A Hz Pos A Hz Grav G m/s2

PID Gain Values

Controller Kp Ki Kd Position Velocity Thrust Attitude W Rate X W Rate Y W Rate Z

Magnetometer Matrix

- i=1 i=2 i=3 j=1 j=2 j=3

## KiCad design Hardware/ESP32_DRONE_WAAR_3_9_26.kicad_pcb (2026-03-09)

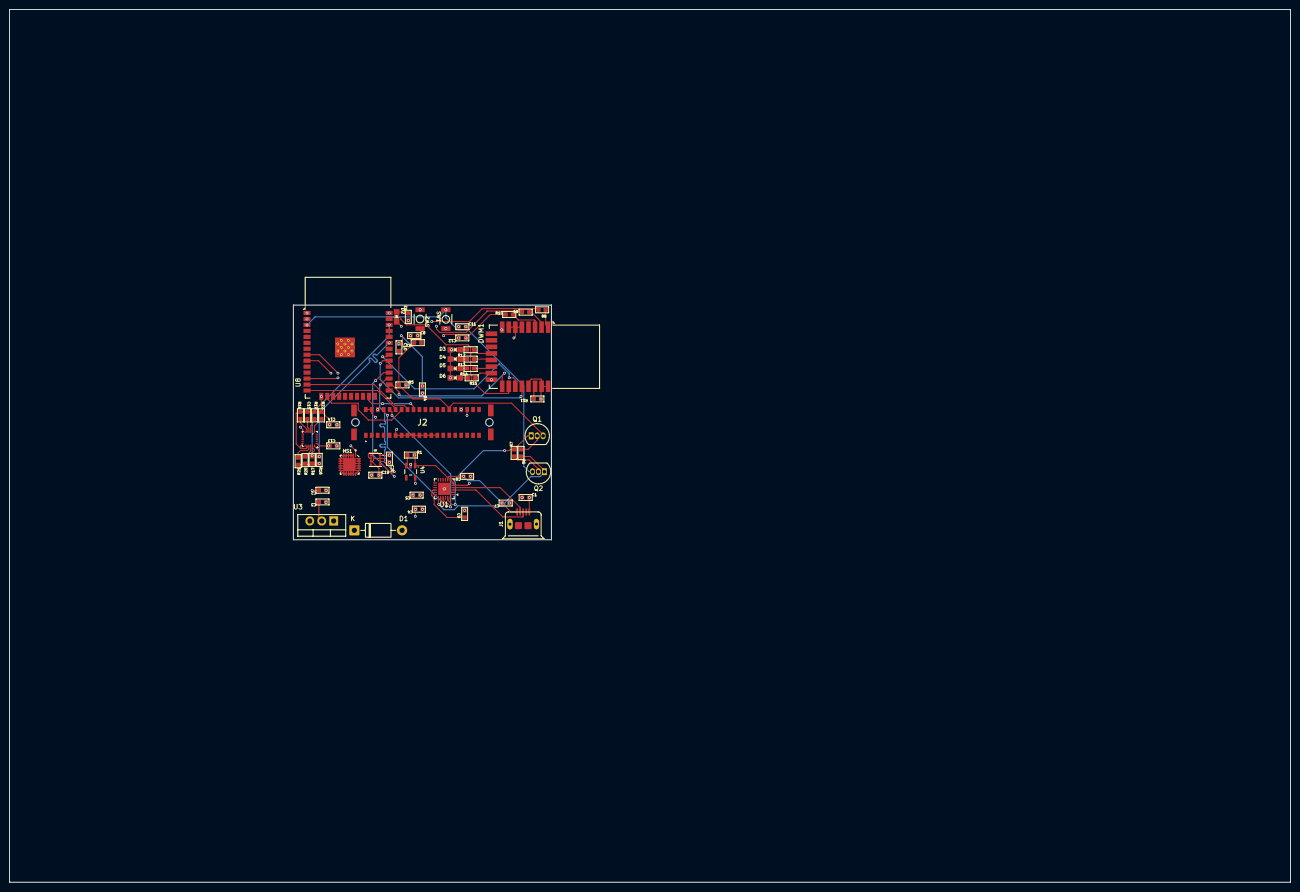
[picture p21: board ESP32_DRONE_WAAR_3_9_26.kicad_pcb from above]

Board: 4 copper layers, 273.0 x 186.0 mm, 59 parts (0 on the bottom side), 54 nets.

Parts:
C1, C2, C3, C4, C6, C8, C9, C11: 10µF; C0603
C5: 1.0µF; C0603
C7, C10: 100nF; C0603
C12: 0.1µF; C0603
C13: 0.01uf; C0603
C14: 0.1uf; C0603
C15: 0.1uF; C0603
C19: 0.1 uF; C0603
C20: 1 uF; C0603
D1: 1N4005; D_DO-41_SOD81_P10.16mm_Horizontal
D2, D3, D4, D5, D6: LED; CHIPLED_0805_NOOUTLINE
DWM1: DWM3000; DWM1000
HS1: Heatsink_Pad; QFN24_4MM_SMSC
J1: USB_B_Micro; MICRO-USB-5P
J2: Conn_02x20_Odd_Even_MountingPin; 204632E
Q1, Q2: S8050; TO-92_Inline
R1, R4, R5, R11, R16, R17, R18, R19, R20, R21, R22: 10k; 0603
R2, R3: 470; 0603
R6, R7, R8, R9, R10: 1k; 0603
R12, R13, R14, R15: 470R; 0603
SW1, SW2: SW_MEC_5G; 157SW
U1: CP2104; QFN-24-1EP_4x4mm_P0.5mm_EP2.6x2.6mm
U3: LD1117V33; TO-220-3_Vertical
U4: ME6217C33M5G; SOT23-5
U5: MPU-9250; InvenSense_QFN-24_3x3mm_P0.4mm
U7: BME280; PSON65P250X250X100-8N
U8: ESP32-WROOM-32

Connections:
3V3: C1.2, C5.1, C8.1, C11.1, C12.2, C13.1, C14.1, C19.1, C20.1, D2.2 (A), DWM1.5 (VDDAON), DWM1.6 (VDD3V3), DWM1.7 (VDD3V3), J2.34, R4.1, R5.1, R16.1, R17.2, R20.2, R21.2, R22.2, U1.5 (VIO), U1.6 (VDD), U1.7 (REGIN), U4.5 (Vout), U5.1 (RESV_VDDIO), U5.8 (VDDIO), U5.13 (VDD), U7.2 (CSB), U7.6 (VDDIO), U7.8 (VDD), U8.2 (VDD)
+5V: J2.2, J2.4, J2.36
/<NO NET>: DWM1.19 (SPIMISO), U8.31 (IO19)
/CLOCK: R1.2, U4.3 (CE)
/DTR: Q1.1 (E), R7.1, U1.23 (~DTR)
/IO0: J2.30, Q1.3 (C), R2.1, R5.2
/IO4: DWM1.17 (~SPICS), U8.26 (IO4)
/IO18: DWM1.20 (SPICLK), U8.30 (IO18)
/IO23: DWM1.18 (SPIMOSI), U8.37 (IO23)
/IO27: R10.2, U8.12 (IO27)
/IO32: R9.1, U8.8 (IO32)
/IO33: R8.1, U8.9 (IO33)
/IO34: DWM1.22 (IRQ/GPIO8), R11.1
/LEDRX: DWM1.13 (GPIO2/RXLED), R13.1
/LEDRXOK: DWM1.15 (GPIO0/RXOKLED), R15.1
/LEDSFD: DWM1.14 (GPIO1/SFDLED), R14.1
/LEDTX: DWM1.12 (GPIO3/TXLED), R12.1
/PWM1: J2.12, U8.14 (IO12)
/PWM2: J2.14, U8.16 (IO13)
/PWM3: J2.16, U8.13 (IO14)
/PWM4: J2.18, U8.23 (IO15)
/RESET: Q2.3 (C), SW1.1 (A), U8.3 (EN)
/RTS: Q2.1 (E), R6.1, U1.19 (~RTS)
/RXD: J2.8, U1.20 (RXD)
/TXD: J2.10, U1.21 (TXD)
/VBUS: C4.1, C6.1, C7.1, D1.2 (A), J1.1 (VBUS), R1.1, U1.8 (VBUS), U4.1 (Vin)
/VDDV5: C2.1, D1.1 (K), U3.3 (VI)
GND: C1.1, C2.2, C3.2, C4.2, C5.2, C6.2, C7.2, C8.2, C9.2, C10.2, C11.2, C12.1, C13.2, C14.2, C15.2, C19.2, C20.2, D3.1 (K), D4.1 (K), D5.1 (K), D6.1 (K), DWM1.8 (VSS), DWM1.16 (VSS), DWM1.21 (VSS), DWM1.23 (VSS), DWM1.24 (VSS), HS1.1, J1.5 (GND), J2.6, J2.11, J2.13, J2.15, J2.17, J2.19, J2.21, J2.23, J2.25, R3.2, R11.2, R18.2, R19.2, SW1.2 (A), SW2.2 (A), U1.2 (GND), U1.25 (GND), U3.1 (GND), U4.2 (Vss), U5.18 (GND), U5.20 (RESV_GND), U7.1 (GND), U7.7 (GND), U8.1 (GND), U8.15 (GND), U8.38 (GND), U8.39 (GND)
unnamed: C10.1, R4.2
unnamed: D2.1 (K), R3.1
unnamed: D3.2 (A), R12.2
unnamed: D4.2 (A), R13.2
unnamed: D5.2 (A), R14.2
unnamed: D6.2 (A), R15.2
unnamed: DWM1.1 (EXTON), R8.2
unnamed: DWM1.2 (WAKEUP), R9.2
unnamed: DWM1.3 (~RST), R10.1
unnamed: J1.3 (D+), U1.3 (D+)
unnamed: J1.2 (D-), U1.4 (D-)
unnamed: Q1.2 (B), R6.2
unnamed: Q2.2 (B), R7.2
unnamed: R2.2, SW2.1 (A)
unnamed: C9.1, U1.16 (VPP)
unnamed: C3.1, U3.2 (VO)
unnamed: R19.1, U5.9 (AD0/MISO)
unnamed: R22.1, U5.7 (AUX_CL)
unnamed: R21.1, U5.21 (AUX_DA)
unnamed: R18.1, U5.11 (FSYNC)
unnamed: C15.1, U5.10 (REGOUT)
unnamed: R20.1, U5.22 (~CS)
SCL_BME: U7.4 (SCK), U8.28 (IO17)
SCL_IMU: R17.1, U5.23 (SCL/SCLK), U8.36 (IO22)
SDA_BME: U7.3 (SDI), U8.27 (IO16)
SDA_IMU: R16.2, U5.24 (SDA/MOSI), U8.33 (IO21)

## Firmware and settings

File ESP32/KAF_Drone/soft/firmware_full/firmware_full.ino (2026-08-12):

#include "kaf_quadcopter_code.h"

extern peripheral estimation_reset();
extern bool estimation_step( coordinate* estimate );
extern peripheral commander_reset();
extern void commander_step( const unsigned long currentTime );
extern peripheral pidtuner_reset();
extern void pidtuner_step( void* imuData );
extern void peripheral_commonInit();
extern void peripheral_escsInit();
extern void peripheral_escsLoop();
extern void peripheral_mpu9250Init();
extern void peripheral_mpu9250Loop();
extern void peripheral_dw3000Init();
extern void peripheral_dw3000Loop();
extern void peripheral_esp32Init();
extern void peripheral_wifiInit();
extern void peripheral_wifiLoop();
extern void peripheral_webserverInit();
extern void peripheral_webserverLoop();
extern void peripheral_serialInit();
extern void peripheral_serialLoop();
extern void peripheral_serialStart( unsigned int baudrate );
extern void peripheral_freertosLoopComs();
extern void peripheral_freertosLoopFlight();
extern void peripheral_freertosSetup( void ( *flightTask )( void* ), void ( *comTask )( void* ) );
extern imu common_imu;

void setup() {
  peripheral_serialStart( 115200 );
  firmware_reset();
  peripheral_commonInit();
  peripheral_escsInit();
  peripheral_mpu9250Init();
  //DW3000 init (spiBegin/spiSelect/reset sequence) is confirmed - via a per-stage I2C probe bisection -
  //to break the shared I2C bus immediately, before WiFi is even initialized. WiFi was never the cause;
  //it was just always initialized afterward in every prior test, which looked like correlation. Since
  //the chip never actually comes up anyway (DW_NOT_IDLE every attempt), disabling this entirely is the
  //direct fix - both here and in the comms task below, since the retry logic would otherwise re-break
  //I2C every 10s. Revisit together with real DW3000 bring-up.
  //peripheral_dw3000Init();
  peripheral_wifiInit();
  peripheral_webserverInit();
  peripheral_esp32Init();
  peripheral_serialInit();
  firmware_registerPeripheral( estimation_reset() );
  firmware_registerPeripheral( commander_reset() );
  firmware_registerPeripheral( pidtuner_reset() );
  flight_positionEstimator( &estimation_step );
  peripheral_freertosSetup( []( void* pvParameters ) {
    for(;;) {
      peripheral_freertosLoopFlight();
      peripheral_mpu9250Loop();
      pidtuner_step( &common_imu );
      flight_step( &common_imu );
      peripheral_escsLoop();
    }
  }, []( void* pvParameters ) {
    for(;;) {
      peripheral_freertosLoopComs();
      //peripheral_dw3000Loop();
      peripheral_serialLoop();
      peripheral_wifiLoop();
      peripheral_webserverLoop();
      commander_step( millis() );
    }
  } );
}

void loop() {
  //Arduino's loopTask runs this on core 1 at priority 1, the same core and priority as com_task -
  //an empty busy-spinning loop() would keep grabbing scheduler time slices from com_task instead of
  //yielding them, so give it back explicitly.
  delay( 1 );
}

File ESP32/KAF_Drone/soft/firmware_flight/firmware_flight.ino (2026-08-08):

#include "kaf_quadcopter_code.h"

extern void peripheral_commonInit();
extern void peripheral_mpu9250Init();
extern void peripheral_mpu9250Loop();
extern void peripheral_escsInit();
extern void peripheral_escsLoop();
extern peripheral estimation_reset();
extern bool estimation_step( coordinate* write );
extern imu common_imu;
extern void peripheral_serialStart( unsigned int baudrate );

void setup() {
  //init
  peripheral_serialStart( 115200 );
  firmware_reset();
  peripheral_commonInit();
  peripheral_mpu9250Init();
  peripheral_escsInit();
  firmware_registerPeripheral( estimation_reset() );
  flight_positionEstimator( &estimation_step );
}

void loop() {
  static unsigned long prevTime;
  unsigned long currentTime = millis();
  common_imu.timeStep = ( currentTime - prevTime ) * 1e-3F;
  prevTime = currentTime;
  peripheral_mpu9250Loop();
  flight_step( &common_imu );
  peripheral_escsLoop();
}

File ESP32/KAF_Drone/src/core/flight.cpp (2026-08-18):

#include "flight.h"

#if ALT_DEFINE
#define NAN 0.0F
#define isfinite( arg ) true
static float sqrtf( float arg );
static float fmodf( float arg0, float arg1 );
static float atan2f( float y, float x );
static float cosf( float arg );
static float sinf( float arg );
static float expf( float arg );
#else
#include <math.h>
#endif

/*       ^ +y
     O1  |  O0  
       \___/
 -x <- |___| -> +x
       /   \
     O3  |  O2
         v -y    
 cosz, -sinz,     0
 sinz,  cosz,     0
   0,      0,     1
1 - qy * qy,     qx * qy,     qc * qy 
    qx * qy, 1 - qx * qx,    -qc * qx
   -qc * qy,     qc * qx, 1 - qx * qx - qy * qy
*/

#define BOUND( V, LB, UB ) V < UB ? ( V > LB ? V : LB ) : UB
#define PI 3.14159265359F //pi
#define TU 6.28318530718F //2*pi
#define S2 1.41421356237F //sqrt(2)
#define S8 0.35355339059F //sqrt(2)/4
#define P2 9.86960440109F //pi^2
#define AF 13.1000000000F //alpha
#define EF 1e-14F         //epsilon

//simple calibrated filter definition
struct measfilter {
  unsigned int count;
  float total;
  float deviation;
  float previous;
};

//low pass butterworth filter definition
struct lowpass {
  float internal;
  float lowpass;
};

//pid definition
struct pid {
  float intlimit;
  float outlimit;
  float integ;
  float prevmeas;
  lowpass deriv;
};

static struct {//DRONE CONTROL DATA
  float rotMat[9];
  float accelZ;
  unsigned int calibTimeCount;
  unsigned int posTimeCount;
  float calibTimeTotal;
  float yawOffset;
  coordinate estimate;
  coordinate acceleration;
  pid positionPID[3];
  pid velocityPID[3];
  pid attitudePID[3];
  pid attiratePID[3];
  pid acclratePID;
  lowpass gyroLowpass[3];
  measfilter accelCalib[3];
  measfilter gyroCalib[3];
  measfilter magCalib[3];
  measfilter sensorCalib[ FPARLEN( kafenv.cal.sensefilt ) ];
  bool( *estimator )( coordinate* );
} flight;

static void lowpassReset( lowpass* lowpass ) {
  lowpass->internal = NAN;
  lowpass->lowpass = NAN;
}

static float lowpassStep( lowpass* lowpass, const float measured ) {
  lowpass->internal -= S2 * ( lowpass->internal + S8 * ( lowpass->lowpass - measured ) );
  FPGUARD( lowpass->internal, 0 );
  lowpass->lowpass += lowpass->internal;
  FPGUARD( lowpass->lowpass, 0 );
  return lowpass->lowpass;
}

static void pidReset( pid* pid ) {
  pid->integ    = NAN;
  pid->prevmeas = NAN;
  lowpassReset( &pid->deriv );
}

static float pidStep( const coordinate* pidval, pid* pid, const float desired, const float measured, const float dt ) {
  const float error = desired - measured;
  const float deriv = lowpassStep( &pid->deriv, ( pid->prevmeas - measured ) / dt );
  pid->prevmeas = measured;
  pid->integ = pid->integ + error * dt;
  FPGUARD( pid->integ, 0 );
  pid->integ = BOUND( pid->integ, -pid->intlimit, pid->intlimit );
  const float output = pidval->Kp * error + pidval->Ki * pid->integ + pidval->Kd * deriv;
  return BOUND( output, -pid->outlimit, pid->outlimit );
}

static void filterReset( measfilter* filter ) {
  filter->count = 0;
  filter->total = 0;
  filter->deviation = 0;
  filter->previous = 0;
}

static float filterStep( const coordinate* filterval, measfilter* filter, const float measured ) {
  float corrected = measured - filterval->ofst;
  FPGUARD( filter->previous, corrected );
  const float prevMeas = filter->previous;
  const float error = corrected - prevMeas;
  float sig = error * error;
  sig = sig * sig * sig;
  corrected = prevMeas + ( sig / ( sig + filterval->stdv + EF ) ) * error;
  filter->previous = corrected;
  return filterval->gain * corrected;
}

static float filterCalibrate( coordinate* filterval, measfilter* filter, const float measured ) {
  filter->count++;
  filter->total += measured;
  FPGUARD( filter->total, 0 );
  filterval->ofst = filter->total / filter->count;
  const float measDelta = measured - filterval->ofst;
  filter->deviation += measDelta * measDelta;
  FPGUARD( filter->deviation, 0 );
  const float sig2 = filter->deviation / filter->count;
  filterval->stdv = P2 * sig2 * sig2 * sig2;
  filter->previous = measured;
  return sig2;
}

static void positionEstimate( const float dt ) {
  ITRVEC3( i ) kafenv.state.v.f[i] += dt * flight.acceleration.f[i];
  coordinate pos;
  if( flight.estimator( &pos ) ) {
    DPRINTF( "[F] Position Received: X=[ %.3f, %.3f, %.3f ]\n", pos.x, pos.y, pos.z );
    ITRVEC3( i ) flight.estimate.f[i] = kafenv.cal.positionalpha * ( ( pos.f[i] - kafenv.state.x.f[i] ) / dt - kafenv.state.v.f[i] );
  } else {
    const float dtalpha = dt * kafenv.cal.positionalpha;
    ITRVEC3( i ) flight.estimate.f[i] -= dtalpha * flight.estimate.f[i];
  }
  DPRINTF( "[F] Updated Gain Deltas: D=[ %.3f, %.3f, %.3f ]\n", flight.estimate.x, flight.estimate.y, flight.estimate.z );
  ITRVEC3( i ) {
    kafenv.state.v.f[i] += dt * flight.estimate.f[i];
    kafenv.state.x.f[i] += dt * kafenv.state.v.f[i];
  }
  DPRINTF( "[F] Updated Velocity: V=[ %.3f, %.3f, %.3f ]\n", kafenv.state.v.x, kafenv.state.v.y, kafenv.state.v.z );
  DPRINTF( "[F] Updated Position: X=[ %.3f, %.3f, %.3f ]\n", kafenv.state.x.x, kafenv.state.x.y, kafenv.state.x.z );
}

void flight_rotationMatrix( float matrix[9] ) {
  for( unsigned char i = 0; i < 9; i++ ) {
    matrix[i] = flight.rotMat[i];
  }
}

void* flight_positionEstimator( bool( *estimator )( coordinate* ) ) {
  bool( *previous )( coordinate* ) = flight.estimator;
  if( estimator != NULLPTR ) {
    flight.estimator = estimator;
  }
  return ( void* )previous;
}

float flight_calibrateSensor( const STDBYTE id, const float value ) {
  return id < FPARLEN( kafenv.cal.sensefilt ) ? kafenv.cal.sensefilt[id].gain *
      sqrtf( filterCalibrate( &kafenv.cal.sensefilt[id], &flight.sensorCalib[id], value ) ) : NAN;
}

float flight_filterSensor( const STDBYTE id, const float value ) {
  return id < FPARLEN( kafenv.cal.sensefilt ) ? filterStep( &kafenv.cal.sensefilt[id], &flight.sensorCalib[id], value ) : NAN;
}
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

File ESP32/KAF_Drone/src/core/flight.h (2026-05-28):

#include "kaf_drone.h"

//ID numbers for default flight modes. First three bit of the flight mode are defined
//by the core flight software code, and signify
#define DEFAULT_MODES_MASK   7
#define NULL_MODE            0
#define INACTIVE_MODE        1
#define CALIBRATION_MODE     2
#define ACTUATION_MODE       3
#define MOTOR_SETPOINT_MODE  4
#define ACCEL_SETPOINT_MODE  5
#define POS_SETPOINT_MODE    6
#define TRAJECTORY_MODE      7

struct imu {//FLIGHT DATA
  float timeStep = 0.01F;
  coordinate accelInput = { 0, 0, 0 };
  coordinate gyroInput = { 0, 0, 0 };
  coordinate magInput = { 0, 0, 0 };
  bool accelUpdate = false;
  bool gyroUpdate = false;
  bool magUpdate = false;
};

void flight_rotationMatrix( float matrix[9] );
void* flight_positionEstimator( bool( *estimator )( coordinate* ) );
float flight_calibrateSensor( const STDBYTE id, const float value );
float flight_filterSensor( const STDBYTE id, const float value );

void flight_attitudeEstimate( const imu* sensor );
void flight_attitudeControl( const coordinate a, const float tk, const float dt );
void flight_positionControl( const imu* sensor, const float position[4] );

peripheral flight_reset();
void flight_step( const imu* sensor );

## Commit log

2026-03-06 Updated Temporary PCB Model
    [MONO_CAMERA_VER_1.SLDPRT, TEMPORARY_PCB_HOLDER_WAAR_VER_1.SLDPRT, TEMPORARY_PCB_MODEL_ADAPTER_WAAR_VER_1.SLDPRT]
2026-03-06 Modified Adapter for temp PCB
    [TEMPORARY_PCB_MODEL_ADAPTER_WAAR_VER_1.SLDPRT]
2026-04-03 Up to date models from diego, plus battery model from nick
    [ASSEMBLY_WAAR.SLDASM, BATTERY_MODEL_WAAR_VER_1.SLDPRT, BATTERY_MOUNT_L_WAAR_VER_1.SLDPRT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]
2026-04-04 drone frame not ass anymore and also has cutouts and swag
    [Drone_Frame_WAAR_WIN_VER_4.SLDPRT, Drone_Frame_WAAR_WIN_VER_5.SLDPRT, UPDATED_DRONE_ASSEMBLY.SLDASM]
2026-04-04 longer frame
    [Drone_Frame_WAAR_WIN_VER_5.SLDPRT]
2026-04-17 Firmware kent (#15)
    Nominally functional Infdev version (Ver:20260416)
    [Crazyflie.xlsx]
2026-04-18 Revert "Firmware kent (#15)" (#16)
    This reverts commit 9a3cdc894a2f08e73944c4bd67b5f72e59120bef.
    [Crazyflie.xlsx]
2026-04-18 weights, front camera, leg redesign, battery mount redesign, all screws in assembly
    [92000A004_Passivated 18-8 Stainless Steel Pan Head Phillips Screws.SLDPRT, ASSEMBLY.SLDASM, BATTERY_ARM_WAAR_VER_4.SLDPRT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]
2026-04-19 fixed screw weights, made propellers motors mount exactly perpendicular to the arm
    [ASSEMBLY.SLDASM, DRONE_FRAME_WAAR_WIN_VER_6.SLDPRT, M2.5.SLDPRT]
2026-04-19 removed duplicate screw
    [ASSEMBLY.SLDASM]
2026-04-30 added the new front camera holder and front camera base
    [ASSEMBLY.SLDASM, FRONT_CAMERA_BASE_WAAR_VER_2.SLDPRT, FRONT_CAMERA_BASE_WAAR_VER_3.SLDPRT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]
2026-05-09 added screw to the motors
    [ASSEMBLY.SLDASM]
2026-05-28 Version 20260527 - Final Update
    * Delete ESP32/KAF_Drone directory
    * Add files via upload
2026-05-28 Revert Version
    This reverts commit ce6d1cb842d0ebdbb10785fc6ef1538f62dbbb28.
    [commander.h, common_data.h, communication.cpp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]
2026-05-28 Version 20260527 - Final Firmware Update (#20)
    * Added Webserver files
    * Streamlined simulation code
    * Added auto-pid-tuning features
    * Improved persistent data handling
2026-07-10 Recognizes stereo camera
    Refactor camera initialization to find stereo camera by scanning indices. Update constants and modify main function to use the new camera finding logic.
2026-07-10 Implement forced camera index and improve camera detection
    Added functionality to force camera index and handle camera opening more robustly.
2026-08-01 Temp rename case change
2026-08-02 Most update firmware for ESP32 flight controller
2026-08-02 I2C address modification for BME280
2026-08-07 Switch ESC output from PWM (ESP32Servo) to DShot300 (DShotRMT)
    Replaces the ESP32Servo/LEDC-based writeMicroseconds() calls in
    periph_esc.cpp with DShotRMT, mapping the mixer's 0-1 throttle directly
    to DShot's 0-100% range. Replaces the PWM arm-pulse ramp with a proper
    DShot zero-throttle arming stream, sized to the fixed 100Hz flight loop
    rate (FLIGHT_TASK_PERIOD_MS). Updates the ALT_DEFINE mock in altdef.h
    to match.
    [periph_esc.cpp]
2026-08-07 Add standalone DShot300 ESC bench-test sketch
    Exercises the real peripheral_escsInit()/peripheral_escsLoop() code path
    directly, bypassing IMU/WiFi/webserver/commander, to verify DShot motor
    output independently of the (currently flaky) web UI arming flow.
2026-08-08 Fix boot crash in firmware_flight.ino
    Two bugs combined to cause a Guru Meditation (StoreProhibited) crash
    on every boot:
    1. Serial was never initialized (no Serial.begin()/peripheral_serialStart()
    call anywhere in setup()), yet firmware_reset() calls DPRINTF
    (-> Serial.printf) almost immediately via kaf_reset(). Printing
    through an uninitialized HardwareSerial dereferences a null internal
    handle.
    2. estimation_reset()'s returned peripheral struct was discarded
    (called as a bare statement) instead of being passed to
    firmware_registerPeripheral() as firmware_full.ino does - the
    crash occurred at exactly this point once (1) was fixed.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
    [firmware_flight.ino]
2026-08-08 Add MPU9250 magnetometer calibration
2026-08-08 Fix AK8963 magnetometer axis frame mismatch relative to accel/gyro
    The AK8963 magnetometer die inside the MPU-9250 package has its own
    internal axis frame relative to the accelerometer/gyroscope die (X/Y
    swapped, Z inverted) - a well-documented hardware quirk of this chip.
    Raw magnetometer axes were previously fed directly into the flight
    buffer with no correction, meaning they were not expressed in the same
    frame as accel/gyro data feeding the same attitude/yaw estimator.
    Combines the chip-intrinsic remap with the same board-mounting sign
    correction already applied to accel/gyro, so all three sensors are now
    consistently in the drone's body frame.
    The existing hard/soft-iron calibration m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
    [periph_mpu9250.cpp]
2026-08-08 Add self-contained magnetometer calibration script
    Implements the same general-ellipsoid-fit algorithm the external
    "Magneto" tool uses, so the hard/soft-iron calibration sweep can be
    redone (and re-verified in the future) without depending on an
    external GUI tool or an unrecorded process. Parses raw Serial Monitor
    output directly - paste the log as-is, no manual cleanup needed.
2026-08-08 Fix AK8963 magnetometer register byte order
    AK8963 data registers are little-endian (HXL then HXH), so the low
    byte must go in the low position - the previous code had the shift
    backwards, corrupting every axis reading regardless of the axis-frame
    remap. Also resets the hard/soft-iron calibration matrix to
    identity/zero as a clearly-marked placeholder pending a fresh
    calibration sweep.
    [periph_mpu9250.cpp]
2026-08-08 Fix Ground Station protocol port and message ID mismatches
    Rebuilds this branch on top of current main (which is now the source of
    truth for ESP32/KAF_Drone) and carries forward only the relevant Ground
    Station app work from the earlier WIP commit, dropping the obsolete
    pre-DShot firmware structure and RC_ESC debugging code.
    Fixes remaining protocol mismatches against the firmware:
    - Default/fallback connect port was 80 (HTTP webserver) and 1234,
    should be 70 (the firmware's raw WiFiServer port in periph_wifi.cpp).
    - Connect panel hint text suggested the wrong port.
    comReplyWifi (0x21) and comSetWifi (0x62) were already corrected in the
    earlier WIP work and are carried forward unchanged.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
2026-08-08 Fix soft-iron rotation bug and add AK8963 sample validation
    Two issues found during review of the first calibration attempt's poor
    fit quality (29% relative spread in calibrated magnitude, should be a
    few percent):
    1. magnetometer_calibration.py: the soft-iron matrix was computed as
    sqrt(eigvals) @ eigvecs.T, which correctly maps the distortion
    ellipsoid to a unit sphere but is only one of infinitely many valid
    solutions - it can introduce an arbitrary rotation of the output
    frame that a magnitude-only quality check can't detect, silently
    corrupting yaw even when the fit "looks" good. Switched to the
    symmetric positive-definite square root (eigvecs @ sqrt(eigvals) @
    eig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
    [magnetometer_calibration.py, periph_mpu9250.cpp]
2026-08-08 Fix incorrect rejection of negative-k ellipsoid fits
    The least-squares fit normalizes the quadric equation to a fixed
    constant term of -1, but has no way to know in advance which overall
    sign that normalization will land on for a given dataset. When it
    picks the opposite sign, M comes out negative-definite and k comes out
    negative too - same sign, so M/k is still positive-definite and a
    perfectly valid calibration. The old code rejected k <= 0 outright as
    degenerate, when the eigenvalue check on M/k immediately below is the
    actual (and sufficient) validity test.
    An earlier attempted fix flipped M and n's sign to force k positive,
    which avoided the crash but reused the wrong implicit normali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
    [magnetometer_calibration.py]
2026-08-08 Apply fitted magnetometer hard/soft-iron calibration
    Values from tests/magnetometer_calibration.py against a fresh sweep
    (raw_mag_log_v2.txt), collected with the ST1/ST2-filtering firmware
    and away from motors/metal. Calibrated magnitude across the sweep:
    mean=1.00, std=0.08 (~8% relative spread), replacing the identity/zero
    placeholder.
2026-08-09 Fix DW3000 timing bug and add rate-limited bring-up retry
    sleepms()/sleepus() in the vendor DW3000 port library had their actual
    delay() calls commented out (dead AVR-style placeholders instead), making
    several vendor-required chip-timing waits in dwt_initialise() silent
    no-ops. This was the real cause of the firmware_full.ino "silent except
    ESC" logging corruption: the DW3000 chip, correctly wired and genuinely
    selected over SPI, was being driven without the timing it needed.
    Also verified (and left as originally correct) DW_SS/MPU_SDA/MPU_SCL
    against Makerfabs' own dw3000_board_config.h after initially getting the
    pin mapping wrong from a bad web search result - GPIO21 is not part of
    the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
    [common_data.h, firmware_dw3000test.ino, periph_dw3000.cpp]
2026-08-09 Fix DW3000-vs-I2C bus conflict, FreeRTOS scheduling, and EEPROM layout bugs
    Root cause of the long-standing MPU9250 I2C failures, found via a per-stage
    I2C probe bisection: peripheral_dw3000Init()'s SPI bring-up sequence breaks
    the shared I2C bus immediately, before WiFi is even initialized. WiFi was
    never the cause - it was just always initialized afterward in every prior
    test, which looked like correlation. Since the DW3000 chip never actually
    comes up anyway (DW_NOT_IDLE every attempt), disabled its Init/Loop calls
    in firmware_full.ino entirely as the direct fix; the peripheral code itself
    is untouched for whenever real DW3000 bring-up is revisited.
    Also along the way:
    - Restored FLTSYNC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
    [communication.cpp, firmware_full.ino, flight.cpp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]
2026-08-09 Wire real ARM/DISARM sequence into Ground Station app, fix landscape layout
    ARM now sends COM_SET_FLIGHTMODE (into ACTUATION_MODE, the one flight_step()
    case that leaves kafenv.cmd.motors alone) followed by COM_SET_ACTUATION
    before starting the motor-command stream - previously ARM only started
    sending COM_SET_MOTORS packets, which the firmware's default NULL_MODE
    silently discards every 10ms. DISARM sends actuation=false and reverts to
    NULL_MODE as a second line of defense.
    Also fixes a layout bug in the Remote screen's landscape mode: VoiceControlPanel
    was placed in the controls Row with no width constraint, so its unwrapped Text
    rendered wider than expected and squeezed the ARM/DISARM/KI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
2026-08-10 Fix cross-core deadlock: mark triggerLock volatile
    FLTSYNC (comms task) and flight_step()'s tail handshake (flight task,
    other core) busy-wait on kafenv.info.triggerLock to hand off writes to
    shared state safely. Without volatile, the compiler is free to cache a
    stale read of it in either busy-wait loop instead of re-polling memory.
    Confirmed via a targeted diagnostic print: sending COM_SET_FLIGHTMODE
    validated and replied SUCCESS (that reply is generated by a separate,
    non-mutating validation path), but the actual write in the "respond to
    commands from sender" handler never ran - the comms task hung forever
    in FLTSYNC, and the flight task never observed triggerLock go nonzero,
    so it never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
2026-08-10 Fix Ground Station default drone ID, packet coalescing, and TCP flush crash
    Default target drone ID was 0x41 ('A') but firmware_full.ino identifies
    itself as 0x55 ('U'); packets addressed to the wrong ID are silently
    ignored by the firmware (no reply, no error), which was the actual cause
    of ARM appearing to do nothing after an app restart reset the field to
    its default. Fixed the default in both DroneController and the Console
    tab's text field.
    Also add a 60ms gap between ARM/DISARM's two back-to-back sendBytes()
    calls: the firmware's com_step() reads all currently-available TCP bytes
    into one buffer and only processes the first packet in it, so two sends
    with no gap can land in the same r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
2026-08-12 Decouple hover feedforward from apid.Kp, fix motor-mixing and visualization axis mismatches
    Add hoverThrust as a separate calibration field so attitude control's
    thrust feedforward no longer saturates output whenever apid.Kp is
    nonzero - the previous coupling guaranteed max-thrust lockup on arm.
    Fix Ground Station's manual joystick mixing (drone_controller.dart) to
    match flight.cpp's real per-motor sign convention - roll and pitch were
    cross-wired relative to firmware. Fix the webserver attitude canvas's
    motor-vector coordinate indices, which drew M0/M1/M2 at the wrong
    wireframe corners (site/app.js and the embedded periph_webserver.cpp
    copy). Add a body-frame X/Y/Z reference triad to the s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
    [axis_motor_monitor.py, flight.cpp, gflt_snapshot.py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]
2026-08-18 Fix GPS NMEA parsing and wire validated GPS/baro into position estimation
    GPS was a complete no-op despite parsing correctly: the local-origin
    latch flag was set but never advanced past "still recording origin",
    longitude was computed from a slice of the latitude string, cos() was
    called on degrees instead of radians, the local-frame scale factor was
    in km not the metres the rest of the firmware expects (1000x error),
    and x/y were swapped relative to the coordinate struct's own
    documented east/north convention. estimate_position() was a hardcoded
    {0,0,0} stub, and estimation_step() unconditionally returned true with
    a possibly-uninitialized local GPS variable even on ticks with no
    fresh fix.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
    [estimation.h, periph_bme280.cpp, periph_samm10q.cpp]
2026-08-18 Add generic Pi-to-ESP32 trajectory-setpoint protocol and position/comms failsafes
    Adds COM_SET_TRAJSETPT: one fixed-size {sequence, x, y, z, yaw, vx, vy,
    vz} message, shared by both Qualification and Mine Search, so the Pi
    (which now owns trajectory/formation/orbit generation per this
    project's Pi/ESP32/phone split) can hand the ESP32 a moving position
    target without the ESP32 ever generating one itself. Rejects
    non-finite values and non-increasing sequence numbers; timestamps
    receipt with the ESP32's own millis() rather than trusting a
    Pi-supplied clock, since only local arrival time is meaningful for
    staleness detection. Receiving a setpoint updates the target only -
    it never changes fligh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
    [commander.h, communication.cpp, communication.h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]
2026-08-18 Fix missing flight.h include breaking the whole firmware build
    communication.cpp's COM_SET_FLIGHTMODE guard uses
    DEFAULT_MODES_MASK/POS_SETPOINT_MODE/TRAJECTORY_MODE without
    including flight.h, where they're defined - communication.h only
    pulls in kaf_drone.h. Broke compilation of the entire library.
    Same fix already applied on qualification-uwb-relative-position
    (caught there via a real Arduino build), porting to this branch too
    since it hadn't been pushed yet.
    [communication.cpp]
2026-08-18 Bump persistence version to fix stale mpu9250 magCal producing -inf
    This board's persisted magnetometer calibration blob (periph_mpu9250.cpp's
    mpu.magCal, covered by the same version-gated EEPROM check as kafenv/
    commander/pidtuner) was stale - its hard/soft-iron matrix produced -inf
    out of the A*(raw-b) transform every cycle instead of the real,
    calibrated values hardcoded in that file. Bumping the version
    invalidates the whole blob so everything falls back to compile-time
    defaults, same mechanism as the two prior bumps.
    This also resets kafenv.cal's PID gains to defaults - must be manually
    restored via pid_calibrate.py set/save after reflashing.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
2026-08-18 Add onboard Qualification state machine to the ESP32, per revised architecture
    Moves qualification trajectory generation onto the ESP32 itself
    (commander.cpp) instead of the Pi, reusing the existing FLIGHTPATH_*
    primitives (LAUNCH/POSLOCK/CIRCLE/LAND) rather than building a second
    trajectory system. COM_SET_TRAJSETPT (the Pi-to-ESP32 setpoint
    protocol from the previous stage) remains for Mine Search, which
    still needs the Pi's SLAM/planning stack; Qualification no longer
    depends on it.
    Adds:
    - kafenv.info.autonomyMode (MANUAL/QUALIFICATION/MINE_SEARCH) and
    formationSlot (0-3), both phone-set, both rejected while armed so
    they can't change mid-flight. Piggybacks the existing
    COM_REQUES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
    [commander.h, communication.h]
2026-08-18 Add standalone SAM-M10Q GPS bench test script
    Reads raw NMEA off a Matek SAM-M10Q wired directly to a USB-TTL
    serial adapter (not through the ESP32), logs a point on each Enter
    press, and computes local x/y/z using a line-for-line copy of the
    fixed local-frame math from periph_samm10q.cpp - lets the GPS chip
    and this session's coordinate-conversion fix (longitude-string bug,
    missing deg->rad conversion, km/m scale error, x/y swap) be validated
    on the bench independent of flashing/debugging through the drone.
    Applies the same GPS_MIN_SATELLITES/GPS_MAX_HDOP gate the firmware
    uses and flags points that wouldn't have passed it. Logs to CSV for
    comparison against tape-measured reference points.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
2026-08-18 Replace Python GPS bench script with an Arduino sketch
    soft/firmware_gpstest/ (previously an empty placeholder) now has a
    standalone SAM-M10Q bench test that runs on the ESP32 itself, reading
    GPS over the real UART1 pins (common_data.h) with no separate USB-TTL
    adapter and no need to flash the full flight firmware. Logs a point
    each time you type anything + Enter in Serial Monitor, using the same
    fixed local-frame math and quality gate as periph_samm10q.cpp.
    [firmware_gpstest.ino]
2026-08-18 Fix gps_setOrigin() never being called - LAUNCH could never succeed
    gps_setOrigin() was defined but had no caller anywhere in the
    codebase. That meant SENSOR_BUFFER.gps.originSet stayed false
    forever, GPS position was never computed (periph_samm10q.cpp's
    position math is gated on originSet), estimation_positionValid()
    was therefore always false, and both the COM_SET_FLIGHTMODE guard
    and QUALCMD_LAUNCH's own explicit check would reject every attempt
    to enter a position-dependent mode - the whole GPS pipeline and the
    qualification LAUNCH gate were a dead end despite compiling fine.
    QUALCMD_LAUNCH now calls gps_setOrigin() before checking validity,
    matching what estimation.h's own comment alre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
2026-08-18 Add Square Test mode and finish its Ground Station UI
    Square Test is a simpler GPS+BME position-hold validation maneuver
    (climb, fly a 4-corner square, return to launch origin, land) meant
    to exercise position control before ever attempting Qualification's
    real circular orbit - not part of the competition itself.
    ESP32 (commander.cpp/h, kaf_drone.h/cpp, communication.h):
    - AUTONOMY_SQUARE_TEST as a 4th autonomyMode, SQUARE_BOOT..SQUARE_
    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
2026-08-18 Add pre-flight sensor status check before LAUNCH/START
    Adds a per-sensor health bitfield (kafenv.info.sensorStatus: GPS/
    Barometer/IMU/Magnetometer) recomputed every commander_step() tick
    and exposed via the existing COM_REQUEST_INFO telemetry. Distinct
    from estimation_positionValid()/gps_isFixGood()'s use in the actual
    mode-entry gates - this is purely a display aid so an operator can
    see WHICH sensor is the problem before a launch attempt, instead of
    a bare rejection with qualState stuck at BOOT and no explanation.
    Small accessor functions added per peripheral (periph_mpu9250.cpp's
    imuworking/magworking, periph_bme280.cpp's working, and a new
    gps_isFixGood() in periph_samm10q.cpp - qualit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
    [commander.h, estimation.h, periph_bme280.cpp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]
2026-10-15 Track CAD files with Git LFS
2026-10-15 CAD: Oct 2026 drone update
2026-10-15 CAD: remove superseded parts and add flight controller holder
2026-10-16 PCB: add latest flight controller (5/16/26) and shared KiCad libraries under Hardware/PCB
2026-10-16 Store KiCad sch/pcb in LFS and make CAD + PCB files lockable
2026-10-19 Add Vicon mocap position source, lab-router WiFi, relay PID autotune
    - firmware_vicon sketch + mocap.cpp: Vicon positions over WiFi (COM_SET_MOCAP)
    - WiFi joins lab router from gitignored wifi_credentials.h, falls back to AP
    - Relay (Astrom-Hagglund) rate-loop autotune in pid_tuner.cpp + tests/relay_autotune.py
    - ESC_RAMP 0.1 -> 2.0 %/loop; fix pid_calibrate.py set (missing 'c' prefix)
    - tests/vicon: vicon_link.py (vicon/monitor/bridge), kaf_link.py, README
2026-10-20 FRAME: add holder for Lonely Binary Devboard adapter
2026-10-20 Update Autonomy from Sidd-autonomy+coordination
    Bring main's Autonomy/ tree up to date with origin/Sidd-autonomy+coordination
    (bfd14fa): restructured autonomy directories, MAS coordinator fixes, the
    stereo RTAB-Map slam_package, drone_hardware_bridge one-drone stack, and
    waar_perception AprilTag mine node.
    Only Autonomy/ is taken; ESP32 firmware and deploy/ changes on that branch
    are not included. Committed __pycache__/*.pyc files are dropped.
2026-10-26 FRAME: add Lonely Binary devboard adapter and update avionics stack
